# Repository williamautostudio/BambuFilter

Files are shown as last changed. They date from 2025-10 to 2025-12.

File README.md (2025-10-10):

# Air Filtration System – User Guide

## Table of Contents
- [Introduction](#introduction)  
- [Description](#description)  
  - [1. 3D Printing and Fan](#1-3d-printing-and-fan)  
    - [1.1 Printed Parts](#11-printed-parts)  
    - [1.2 Standard Components](#12-standard-components)  
    - [1.3 Key Components](#13-key-components)  
    - [1.4 Assembly](#14-assembly)  
  - [2. Fan Control Board](#2-fan-control-board)  
    - [2.1 PCB Layout](#21-pcb-layout)  
  - [3. ESP32 Firmware](#3-esp32-firmware)  
  - [4. Control Board Configuration and Operation](#4-control-board-configuration-and-operation)  
    - [4.1 Initial Configuration](#41-initial-configuration)  
      - [4.1.1 Accessing the Configuration Page](#411-accessing-the-configuration-page)  
      - [4.1.2 Wi-Fi Configuration](#412-wi-fi-configuration)  
      - [4.1.3 Configuration Parameters](#413-configuration-parameters)  
    - [4.2 Operation](#42-operation)  
      - [4.2.1 Web Interface](#421-web-interface)  
      - [4.2.2 Web API](#422-web-api)  
      - [4.2.3 MQTT Commands](#423-mqtt-commands)  
      - [4.2.4 Re-Configuration](#424-re-configuration)

---

## Introduction
Upgrade your **Bambu S1P** or **X1C 3D printer** with a smarter way to breathe clean air.  
This modular air filtration system features a **2-in-1 HEPA13 + activated carbon filter**, effectively removing fine particles and odors.  
Its modular structure allows for quick and easy filter replacement.

Unlike conventional filters, this system supports **intelligent fan control**.  
Connect to **Wi-Fi** to manage the fan remotely — turn it on/off, adjust speed, or monitor real-time status via:

- Built-in **Web UI**
- **RESTful Web API**
- **MQTT protocol** for automation
- Full integration with **Home Assistant**

This project is **fully open-source** and divided into three modular parts:

1. 3D-Printed Housing and Fan  
2. Fan Control Board  
3. ESP32 Firmware

---

## Description

### 1. 3D Printing and Fan

#### 1.1 Printed Parts
A total of **five 3D-printed components** are required.  
All 3D models are published on **MakerWorld** & **Github** — feel free to download and print them.  
If you do not require the fan-control function, you may omit printing the control-board enclosure.

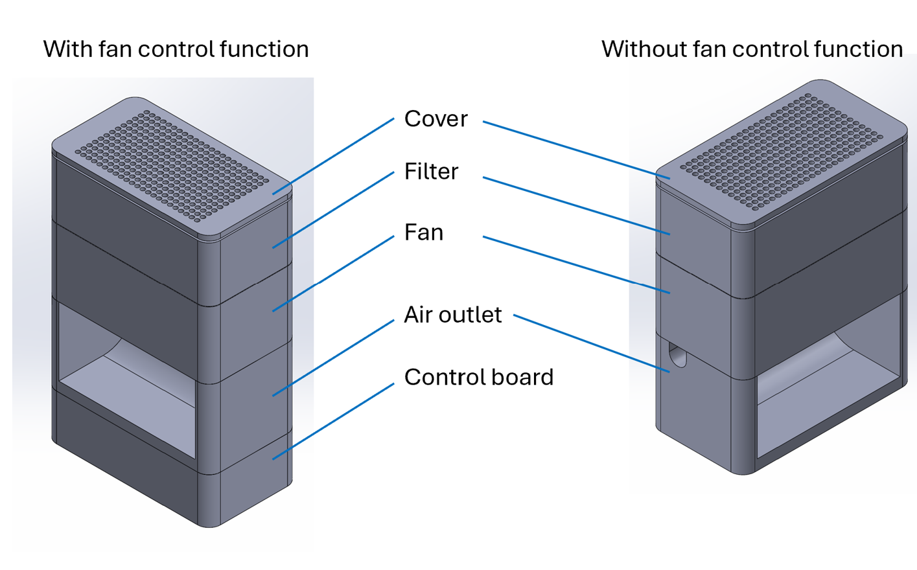
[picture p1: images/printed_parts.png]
Printed Parts


---

#### 1.2 Standard Components

| Item | Spec. / Model | Qty. | Note |
|:---|:---|:---:|:---|
| 1. Fan | 4028 DC 24 V / 4 wire, 18000 rpm | 2 | 1. 2-wire model optional 2. RPM lower than 18000 is fine. |
| 1.1 Screw | M3 × 35 mm | 8 (4) | 2 screws per fan are acceptable |
| 1.2 Nut | M3 | 8 (4) | — |
| 2. Filter | HEPA13 + Activated Carbon Air Filter | 1 | — |
| 3. PCB Board | Ref. Gerber file | 1 | — |
| 3.1 ESP32 | Seeed Studio XIAO ESP32-C3 | 1 | With external antenna |
| 3.2 DC-DC Regulator | MP1584EN DC-DC Regulator | 1 | Input 24 V, Output 5 V |
| 3.3 Terminal | 5.08 mm × 2 P | 3 | — |
| 3.4 IC Socket | 2.54 mm × 7 P | 2 | Optional |
| 3.5 Transistor | C945 (TO-92) | 1 | — |
| 3.6 Resistor | 10 kΩ 1/4 W | 2 | — |
| 3.7 Resistor | 1 kΩ 1/4 W | 1 | — |
| 4. Power Adaptor | Output DC 24 V 1 A | 1 | — |

---

#### 1.3 Key Components
- **Fan** – 4-wire model (2-wire optional)  
  [Where to buy?](https://detail.tmall.com/item.htm?id=695868124936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)
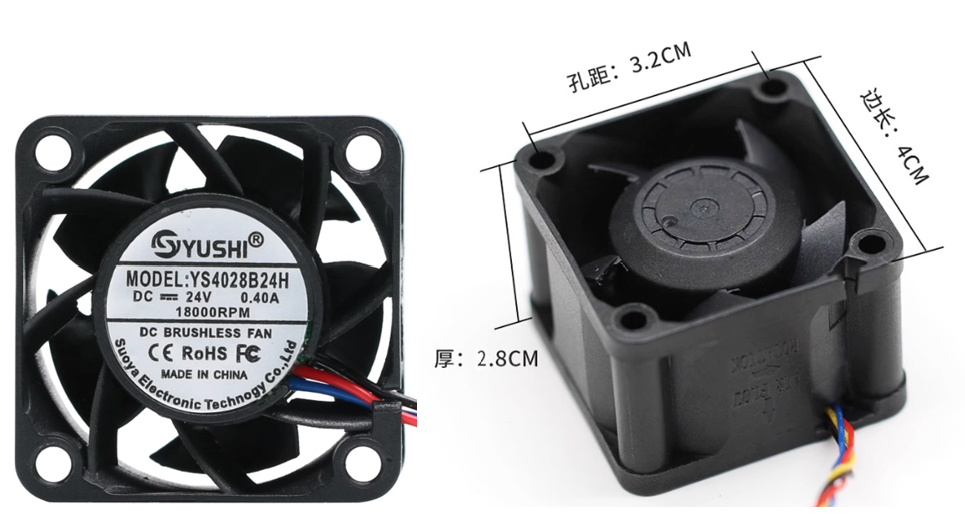
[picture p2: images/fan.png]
Fan
  

- **Filter** – HEPA13 + Carbon  
  [Where to buy?](https://item.taobao.com/item.htm?id=895551373211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)
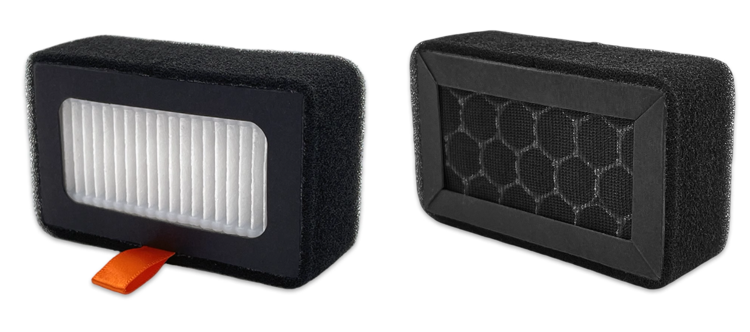
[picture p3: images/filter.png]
Filter
  

- **DC-DC Regulator** – MP1584EN   
  [Where to buy?](https://item.taobao.com/item.htm?id=662919695159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)
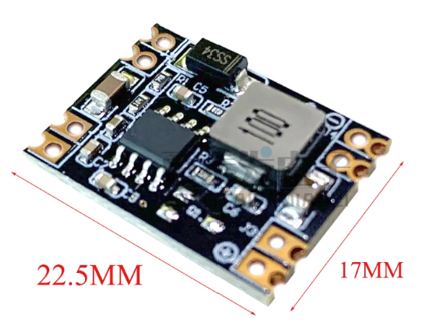
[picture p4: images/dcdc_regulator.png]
DC-DC Regulator
  

- **Seeed Studio XIAO ESP32-C3**   
  [Where to buy?](https://item.taobao.com/item.htm?id=679197017494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)
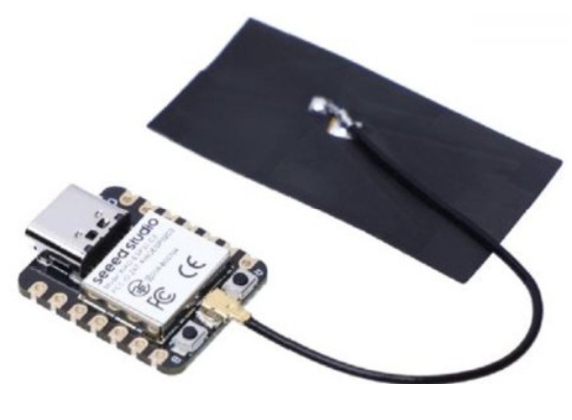
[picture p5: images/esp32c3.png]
ESP32-C3
  

- **Power Adapter** (DC 24 V)  
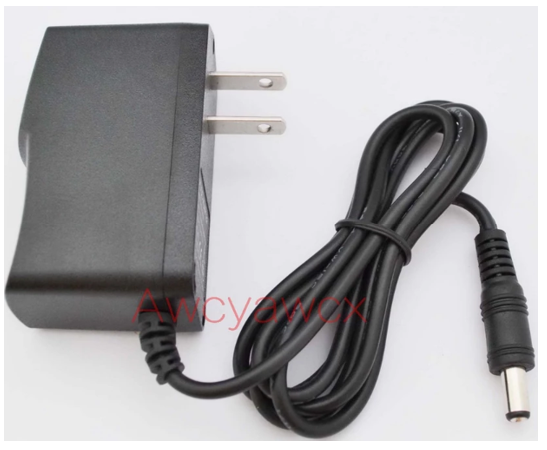
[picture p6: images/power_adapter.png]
Power Adapter
  

---

#### 1.4 Assembly

##### 1.4.1 With Fan Control Function
Install the control board, connect the ESP32, and wire the fan’s PWM control line according to the circuit layout.

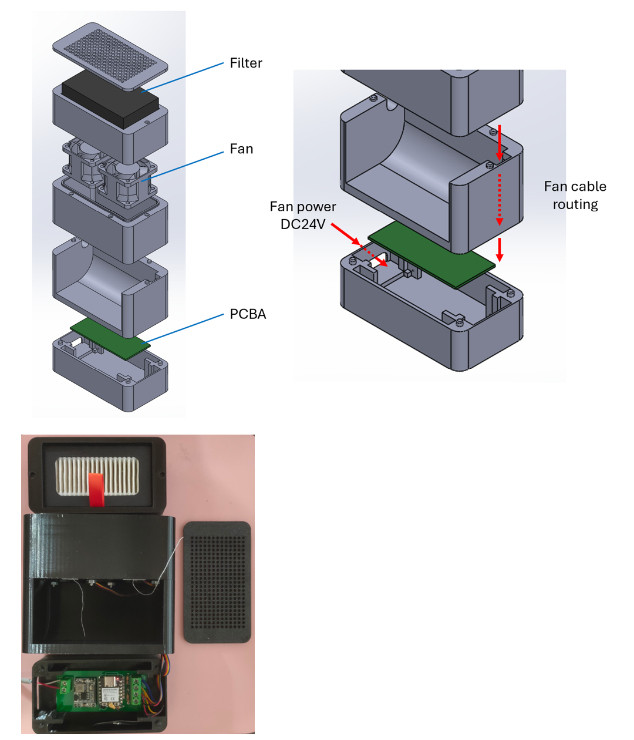
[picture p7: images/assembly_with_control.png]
Assembly With Control


##### 1.4.2 Without Fan Control Function
Connect the fan directly to a **DC 24 V power source** for constant operation.

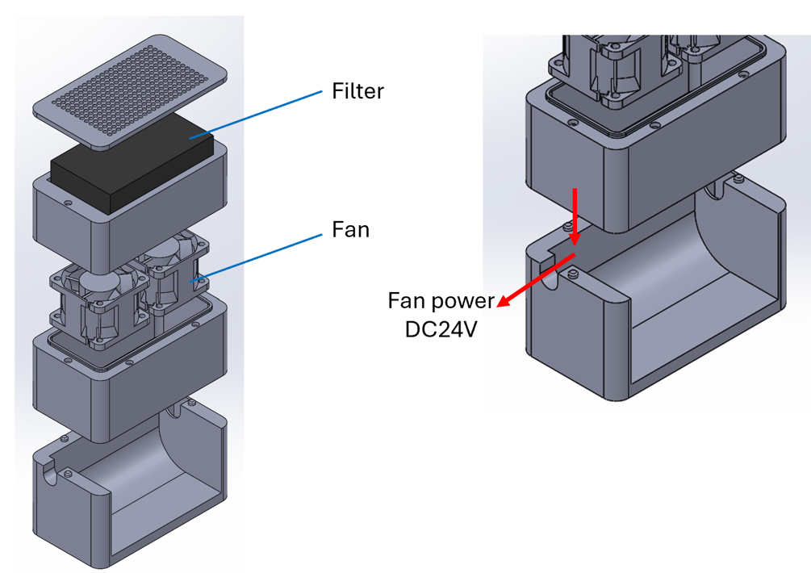
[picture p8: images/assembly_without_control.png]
Assembly Without Control


---

### 2. Fan Control Board

#### 2.1 PCB Layout (70.6 × 31.8 mm)
You may either:

- Solder an **IC socket** to the PCB and insert the ESP32 module, or  
- Solder the **ESP32 directly** to the board for **ease of assembly**.  
[Gerber file](https://github.com/williamautostudio/BambuFilter/tree/main/pcba)
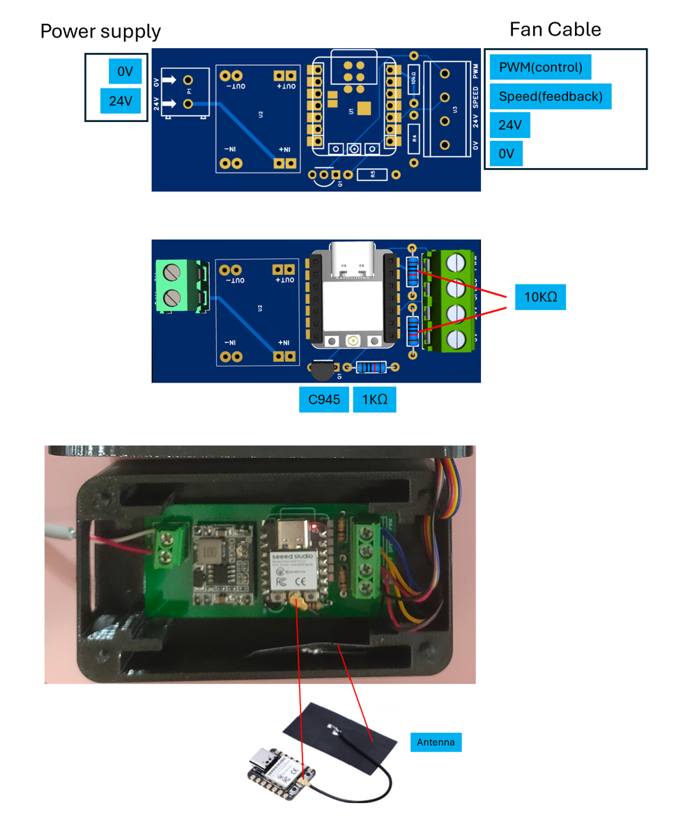
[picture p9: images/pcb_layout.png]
PCB Layout


---

### 3. ESP32 Firmware
Source code is available on [**GitHub**.](https://github.com/williamautostudio/BambuFilter/tree/main/firmware)

To build and upload the firmware:
1. Use **VS Code** with **PlatformIO**.  
2. Follow online tutorials for compiling and flashing if unfamiliar (not covered in this document).

---

### 4. Control Board Configuration and Operation

#### 4.1 Initial Configuration
Upon first power-up, the **ESP32** runs in **AP mode**.  
You can connect via browser to configure Wi-Fi and default fan settings.  

If configuration is skipped, the fan runs with **factory defaults**:
- Default speed : 50 %
- Fan auto-starts after power-on

---

##### 4.1.1 Accessing the Configuration Page
1. Power on the ESP32 —it starts in AP mode with SSID `BambuFanAP`.  
2. Connect your computer or phone to `BambuFanAP`.  
3. Open browser → `http://192.168.4.1` to access the configuration interface.

---

##### 4.1.2 Wi-Fi Configuration
Click **“Configure Wi-Fi”** to open the setup page.

> ⚠️ If the SSID disconnects, reconnect to `BambuFanAP`.  
> The ESP32’s web server may respond slowly — please wait rather than clicking repeatedly.  
> If no response within 3 minutes, **power-cycle** the device and retry.

---

##### 4.1.3 Configuration Parameters
- **Wi-Fi Settings** — SSID and Password  
- **Fan Default Speed** — 15 %–100 % (default 50 %)  
- **Fan Default ON** — whether fan turns on automatically after power-on  
  - `True` = ON by default  
  - `False` = manual activation via Web API / MQTT / Web UI  
- Click **Save** to store settings.

---

#### 4.2 Operation

##### 4.2.1 Web Interface
- **Default ON at Power-Up** – Defines auto-start behavior.  
- **Turn On / Turn Off** – Manual fan control; speed retains last setting.  
- **Fan Speed** – Adjust 15 %–100 %. Below 15 % auto-corrects to 15 %.  
  - If below 25 %, starts at 25 % briefly for stable startup.

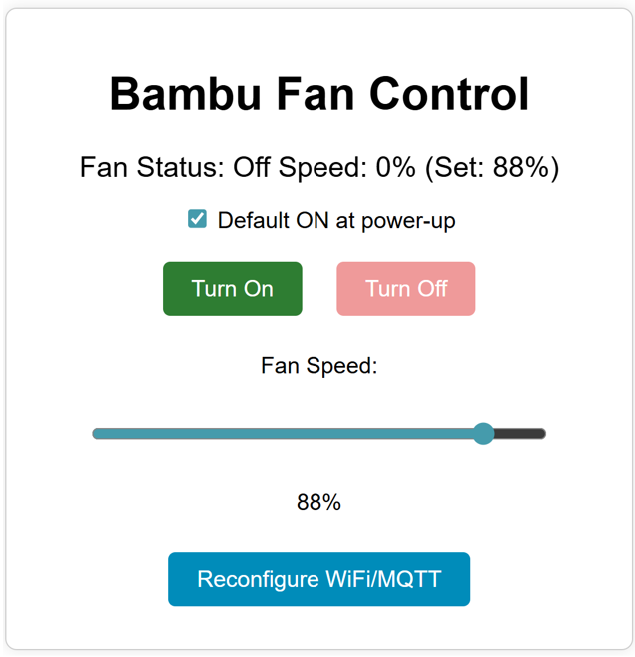
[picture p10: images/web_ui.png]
Web Interface


---

##### 4.2.2 Web API
Assuming ESP32 IP = `192.168.1.2`:

| Function | Endpoint |
|:---|:---|
| Enable Default ON | `http://192.168.1.2/fan?default_on=true` |
| Disable Default ON | `http://192.168.1.2/fan?default_on=false` |
| Turn On Fan | `http://192.168.1.2/fan?state=on` |
| Turn Off Fan | `http://192.168.1.2/fan?state=off` |
| Set Fan Speed 70 % | `http://192.168.1.2/fan?speed=70` |

---

##### 4.2.3 MQTT Commands
- **Default Topic:** `bambu/p1s/fan/cmd`  
- **Payload Format:** Raw numeric value  

**Examples:**
```text
Set speed 70 % → cmd = 70  
Stop fan → cmd = 0
```

---

##### 4.2.4 Re-Configuration
Click **“Reconfigure Wi-Fi / MQTT”** to update settings without rebooting.  

> ⚠️ Note: Each time you enter the configuration page, re-enter Wi-Fi SSID and password.

---

✅ **End of Document**

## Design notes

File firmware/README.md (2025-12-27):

# Bambu P1S Fan Control (ESP32C3)

This project provides firmware for a Seeed XIAO ESP32C3 microcontroller to control a 4-wire PWM fan, specifically designed for use with the Bambu Lab P1S. It connects to WiFi, uses MQTT for communication, and supports Over-The-Air (OTA) updates.

## Features

*   **WiFi Connectivity**: Connects to your local WiFi network, configurable via a web portal if no network is found or if re-configured.
*   **MQTT Control**: Remotely control fan speed via MQTT messages (bidirectional communication).
*   **4-wire PWM Fan Control**: Accurately controls fan speed using PWM.
*   **Active-low PWM**: Handles active-low PWM signals common in 4-wire fans.
*   **Configurable Fan Thresholds**: Adjustable minimum fan speeds for startup and continuous operation.
*   **Over-The-Air (OTA) Updates**: Update firmware wirelessly.
*   **MQTT State Reporting**: Publishes current fan speed (duty and percentage) to an MQTT topic.
*   **Last Will and Testament (LWT)**: Reports device online/offline status via MQTT.
*   **Web Configuration Portal**: Automatically launches a web interface (Access Point: "BambuFanAP", password: "password") for easy setup of WiFi credentials, MQTT server details, and fan default behavior (on/off, speed).
*   **Web Control Interface & HTTP API**: Provides a web page to monitor fan status (on/off, speed), manually turn the fan on/off, and adjust speed. An HTTP API (`/fan?state=on|off`, `/fan?speed=X`, or `/fan?default_on=true|false`) is also available for remote control, including setting the "Default ON at power-up" state.
*   **Reconfigure Option**: A button on the web interface allows the device to re-enter the configuration portal without resetting existing WiFi settings, enabling easy modification of MQTT and fan defaults.
*   **Persistent Fan Speed**: The last set fan speed is stored and used when the fan is turned on.

This project involves a custom PCB design for the fan control.

## Hardware

*   **Microcontroller**: Seeed XIAO ESP32C3
*   **Fan**: 4-wire PWM fan (DC24V 4028 18000rpm)
*   **Power Supply**: DC24V 1A
*   **PCB**: 71x32mm
*   **Fan Control Box**: 3D printed
*   **Filter**: 拓竹HEPA13活性碳空氣濾心(淘寶)

## Software Requirements

*   PlatformIO IDE Extension for VS Code or PlatformIO Core CLI.

## Configuration

All configuration parameters (WiFi credentials, MQTT server details, MQTT username/password, and fan default behavior) are now managed through a web configuration portal provided by `WiFiManager`. This portal automatically launches if the device cannot connect to a known WiFi network, or can be manually triggered via a button on the web control interface.

### Accessing the Configuration Portal

1.  **Automatic**: If the ESP32 cannot connect to a saved WiFi network, it will create an Access Point (AP) named "BambuFanAP" with the password "password". Connect to this AP with your phone or computer.
2.  **Manual**: Access the web control interface (once connected to WiFi) and click the "Reconfigure WiFi/MQTT" button. If the captive portal does not open automatically after connecting to the ESP32 access point, open `http://192.168.4.1` in your web browser.

Once connected to the AP, a captive portal should automatically open in your browser, allowing you to set:

*   **WiFi SSID & Password**
*   **MQTT Server IP/Hostname & Port**
*   **MQTT Username & Password**
*   **Fan Default Speed (0-100%)**
*   **Fan Default ON/OFF**

### PWM/LEDC Settings (Hardcoded)

The following settings are currently hardcoded in `src/main.cpp`:

*   `FAN_PWM_PIN`: GPIO pin connected to the fan's PWM signal (default: 10).
*   `PWM_FREQ_HZ`: PWM frequency in Hz (default: 25000).
*   `PWM_RES_BITS`: PWM resolution in bits (default: 10, for 0-1023 duty cycle).
*   `PCT_MIN_START`: Minimum percentage to start the fan from 0 (default: 25).
*   `PCT_MIN_RUN`: Minimum percentage to keep the fan running (default: 15).

## MQTT Usage

Send messages to `TOPIC_CMD_SPEED` to control the fan:

*   **Percentage (0-100)**: Send a plain number string (e.g., `"60"` for 60% speed).
    *   If the fan is currently off (0 duty) and the new percentage is greater than 0 but less than `PCT_MIN_START`, `PCT_MIN_START` will be used instead.
*   **Raw Duty Cycle (0-1023)**: Send `RAW:<value>` (e.g., `"RAW:512"` for ~50% duty cycle).
*   **JSON Object**: Send a JSON string with `speed` or `percent` field (e.g., `{"speed": 75}` or `{"percent": 75}`).
    *   Similar minimum startup logic applies for percentage values.

The fan's current state (duty cycle and percentage) will be published to `TOPIC_STATE_SPEED`.

## OTA (Over-The-Air) Updates

The device supports OTA updates. Ensure that `upload_protocol = espota` and `upload_port` are correctly configured in `platformio.ini` (e.g., `upload_port = 192.168.2.161`). The hostname for OTA is set to `esp32`.

## Manufacturing information

*   **`image/`**: Contains images related to the project.
    *   `pcb_layout.jpg`: A layout image of the PCB.
    *   `fan_control_box.jpg`: A cutout image of the fan's mechanical components.
    *   `fan.jpg`: A photo of the fan.
    *   `filter.jpg`: A photo of the filter.
*   **`PCB/`**: Contains the Gerber files for the fan control PCB board.
*   **`SolidWorks/`**: Contains the SolidWorks 3D design files for the fan's mechanical components.

## PCB Design

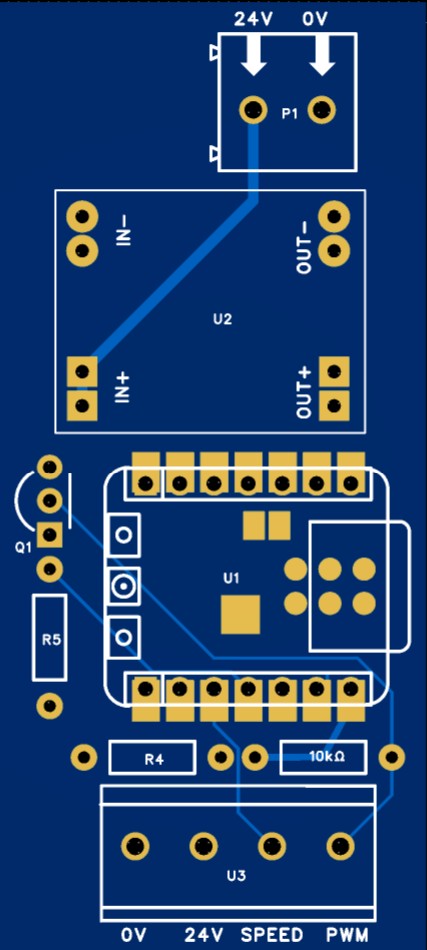
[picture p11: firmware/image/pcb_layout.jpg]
PCB Layout


The PCB layout can be viewed and edited online: [PCB Layout Editor - EasyEDA](https://pro.easyeda.com/editor#id=c79e3e0623a544f8a684775a9b8ccbd5,tab=*d06ea5cc8f37423995d957d8589f9b6b@c79e3e0623a544f8a684775a9b8ccbd5)

## Mechanical Design

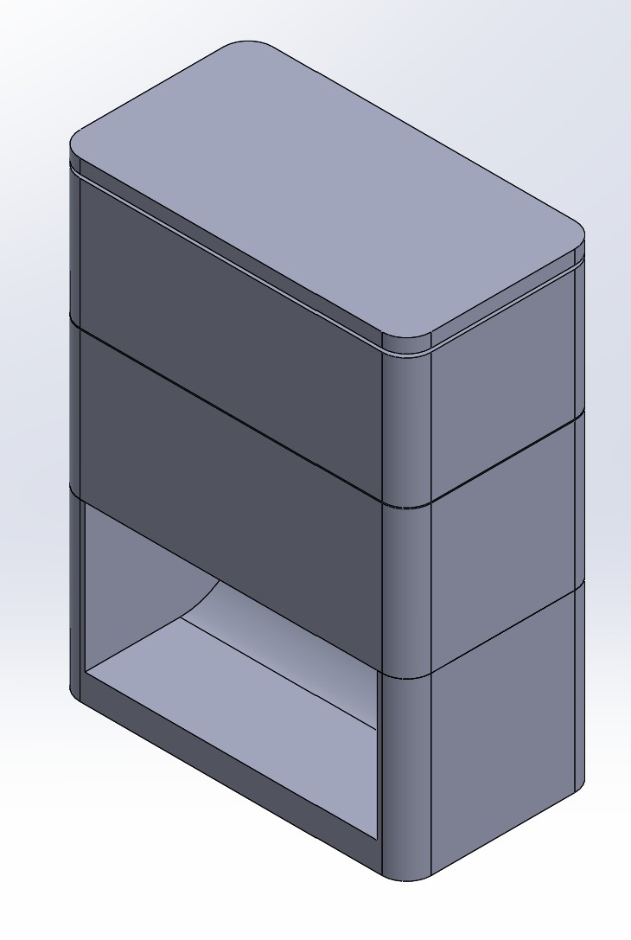
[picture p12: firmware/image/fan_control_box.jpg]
Fan Control Box


## Fan

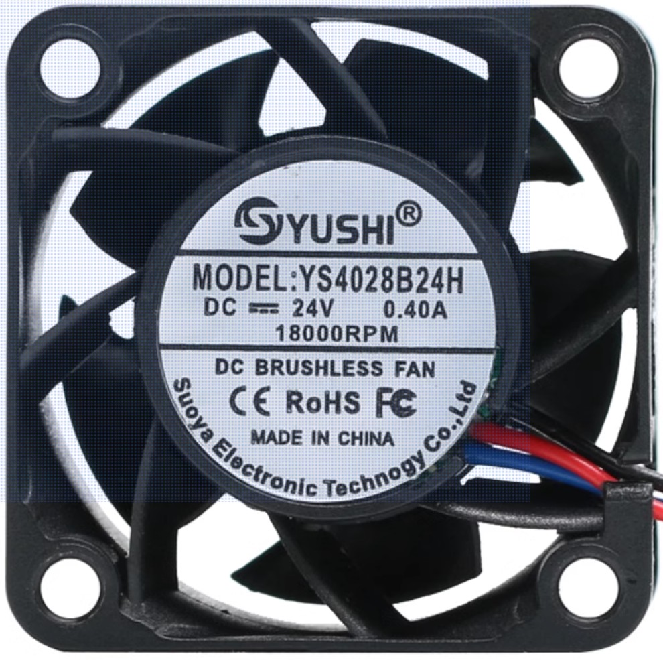
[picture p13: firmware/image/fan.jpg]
Fan

[淘寶](https://detail.tmall.com/item.htm?id=695868124936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)

## Filter

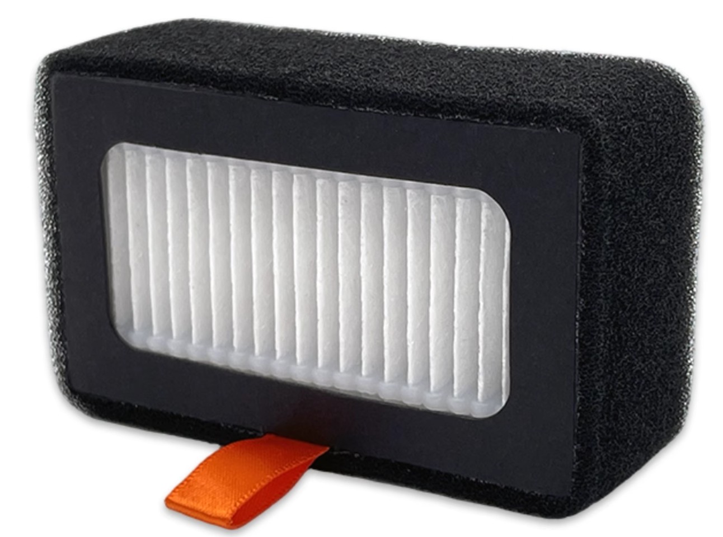
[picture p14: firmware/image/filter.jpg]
Filter

[淘寶](https://item.taobao.com/item.htm?id=895551373211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)

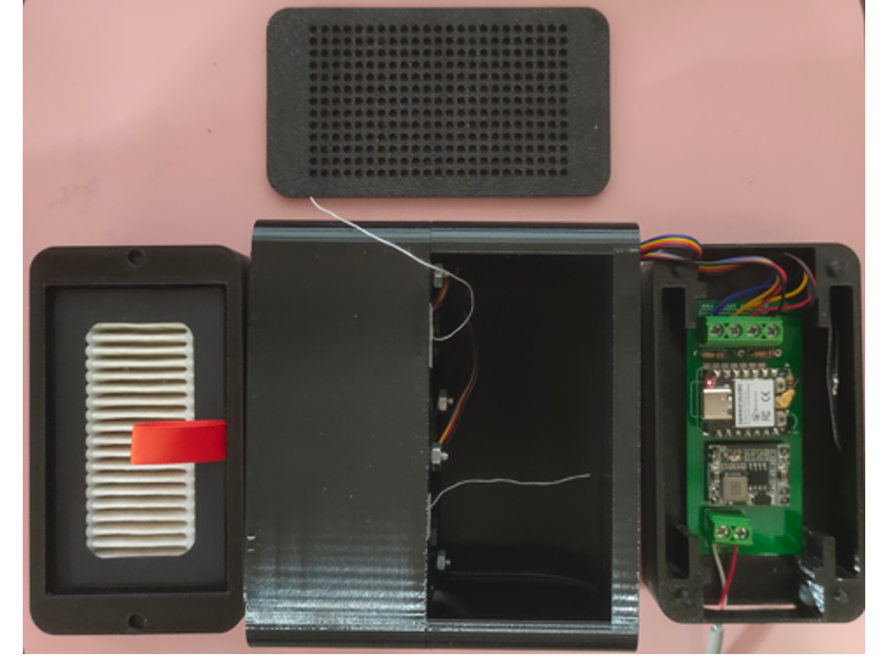
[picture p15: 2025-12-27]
images/cover/Pic3.png

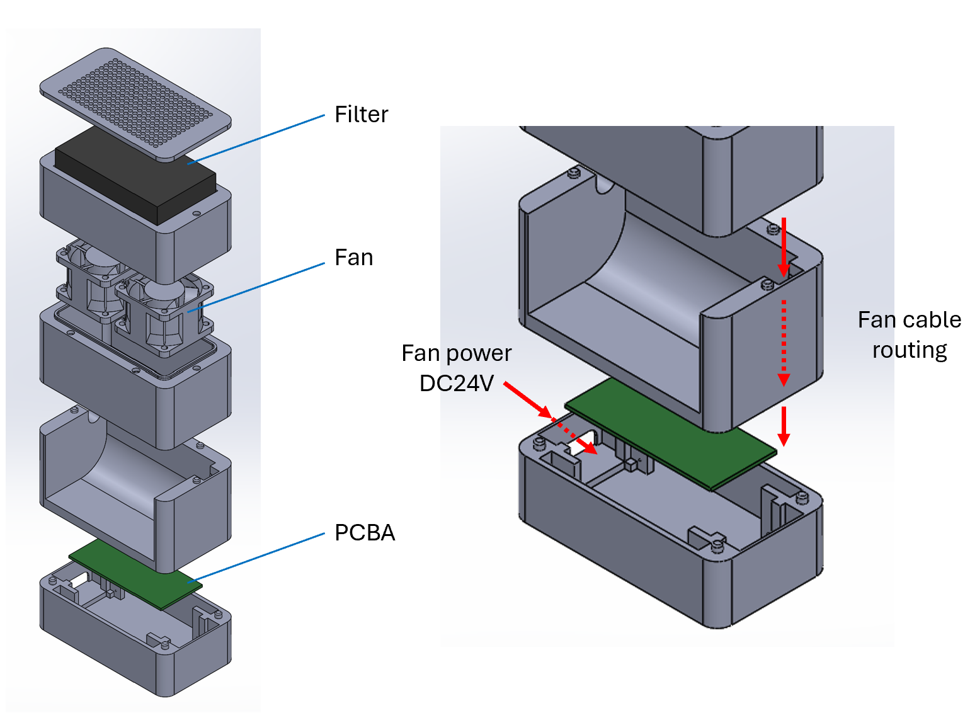
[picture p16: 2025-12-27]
images/cover/Pic1.png

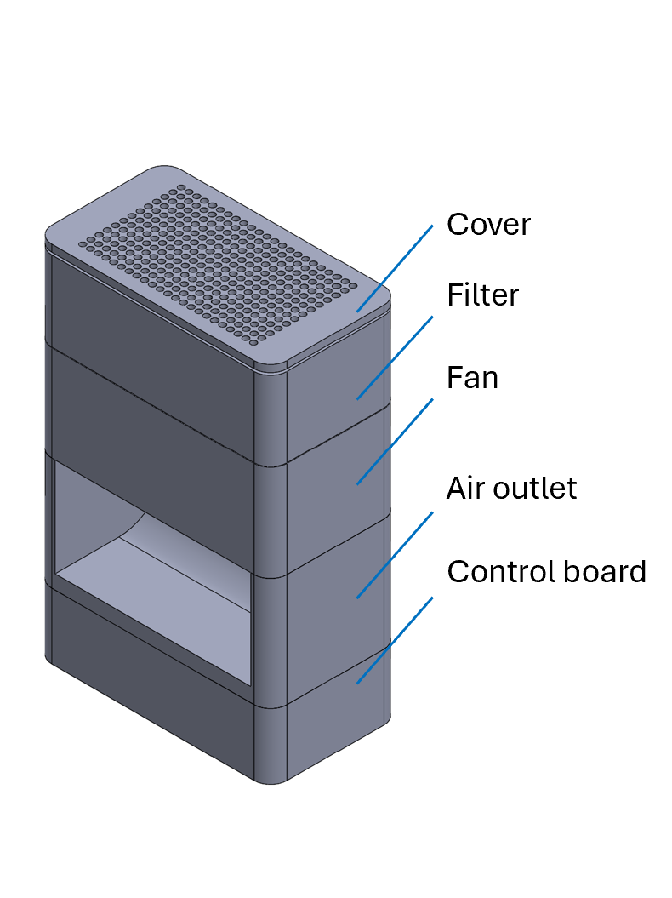
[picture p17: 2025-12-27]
images/cover/cover 3-4.png

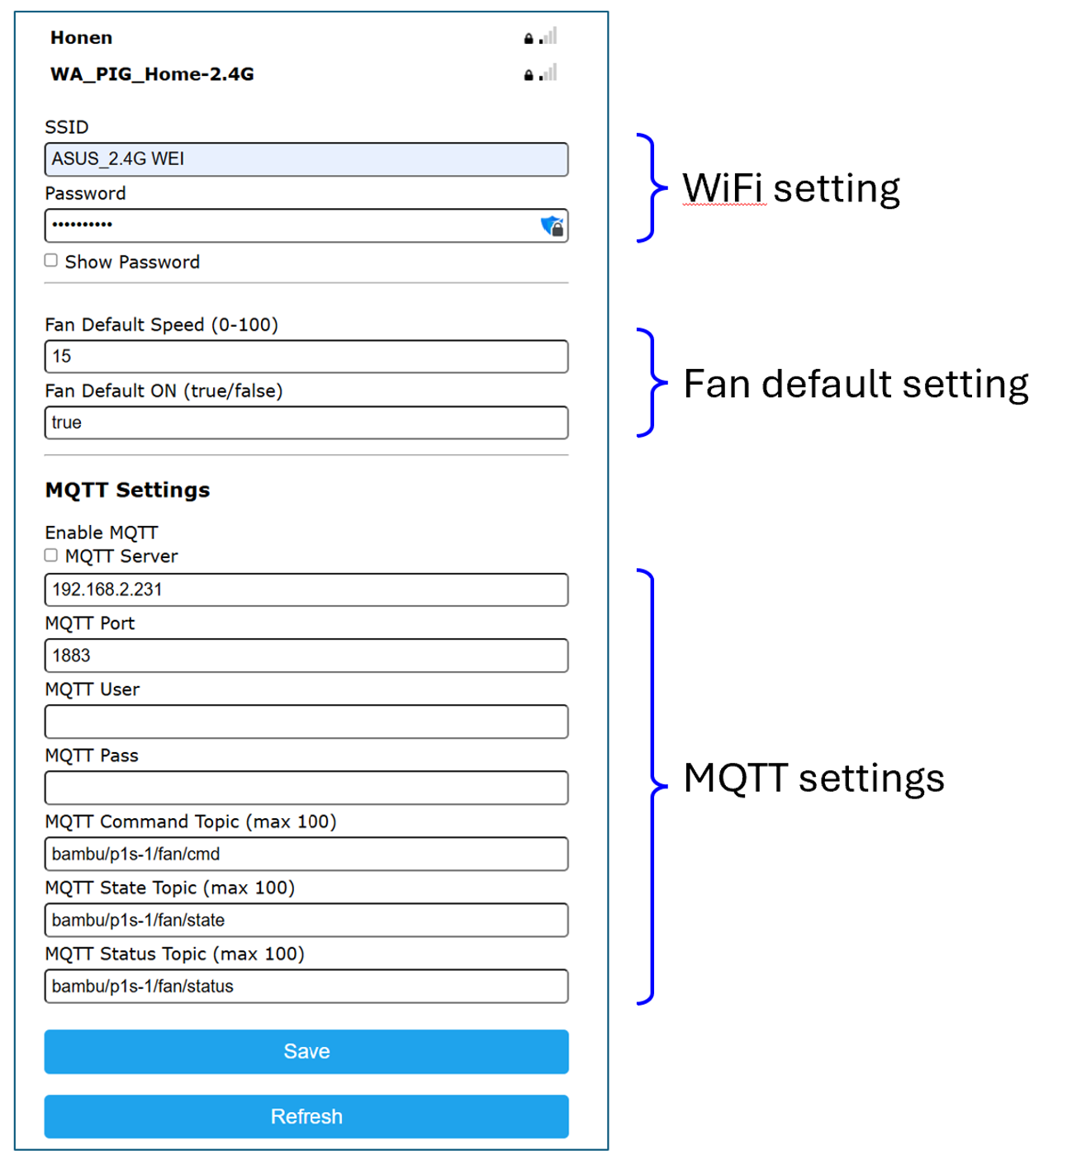
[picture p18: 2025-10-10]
images/parameters.png

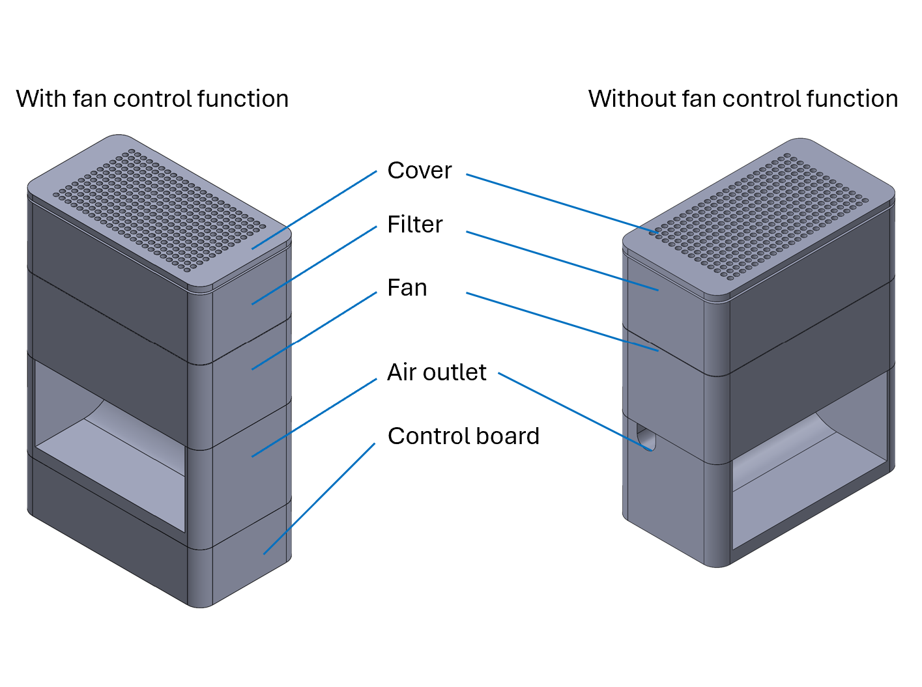
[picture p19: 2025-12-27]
images/cover/cover 4-3.png

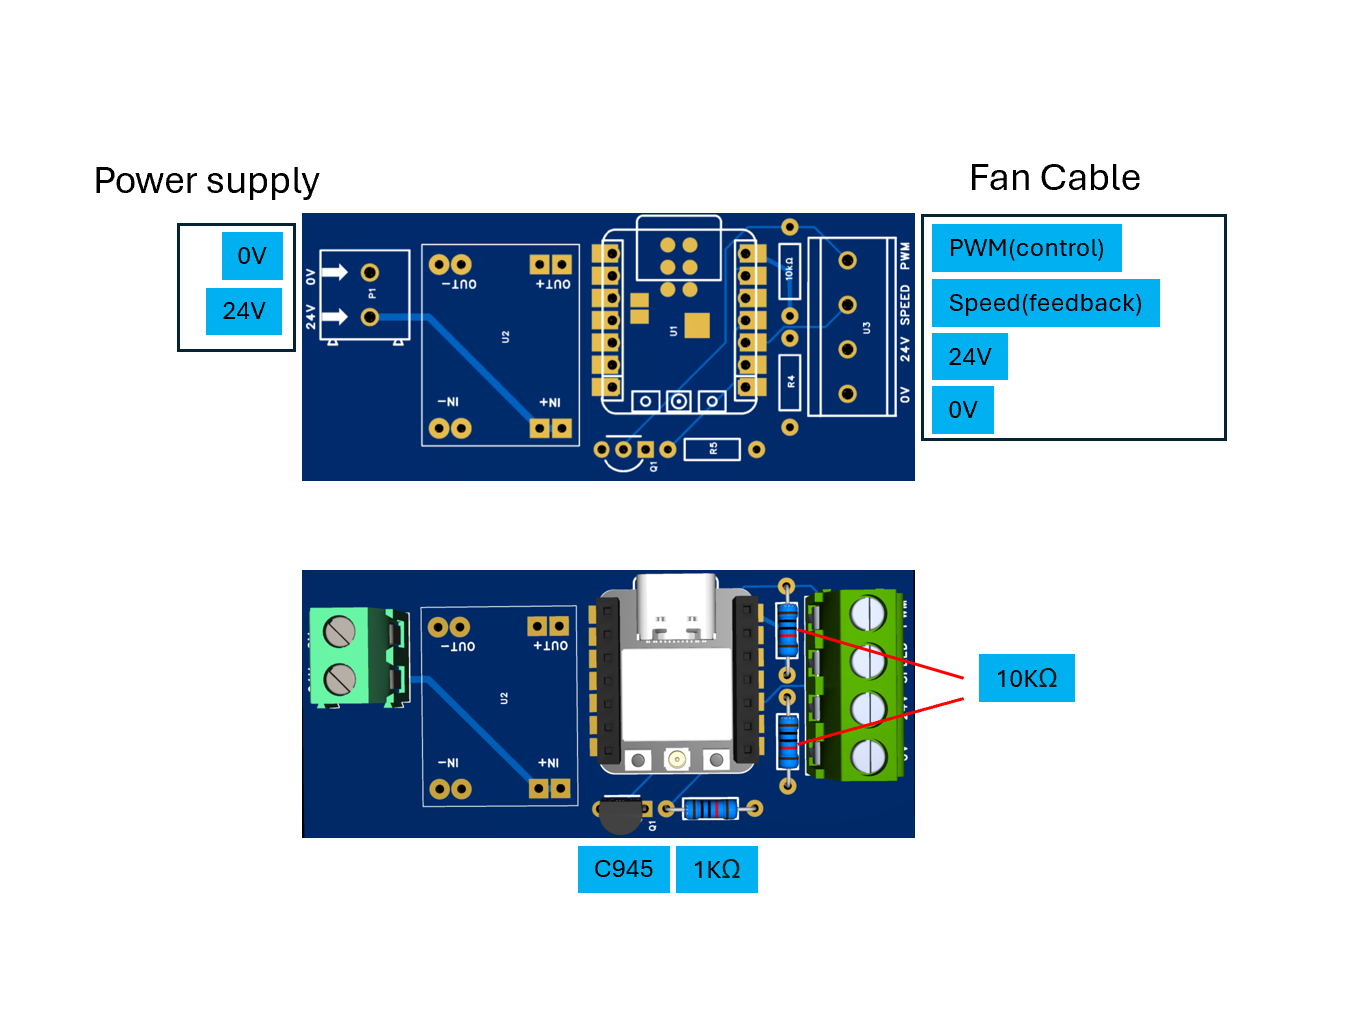
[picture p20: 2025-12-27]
images/cover/Pic4.png

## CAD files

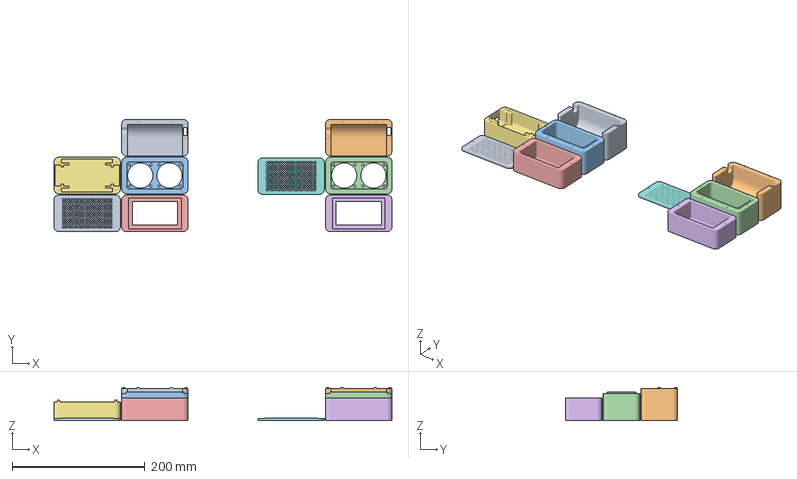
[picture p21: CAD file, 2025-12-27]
Bambu project/Bambu filter.3mf
509.2 x 169.0 x 50.0 mm
air outlet x 2
fan x 2
filter x 2
control board
cover x 2

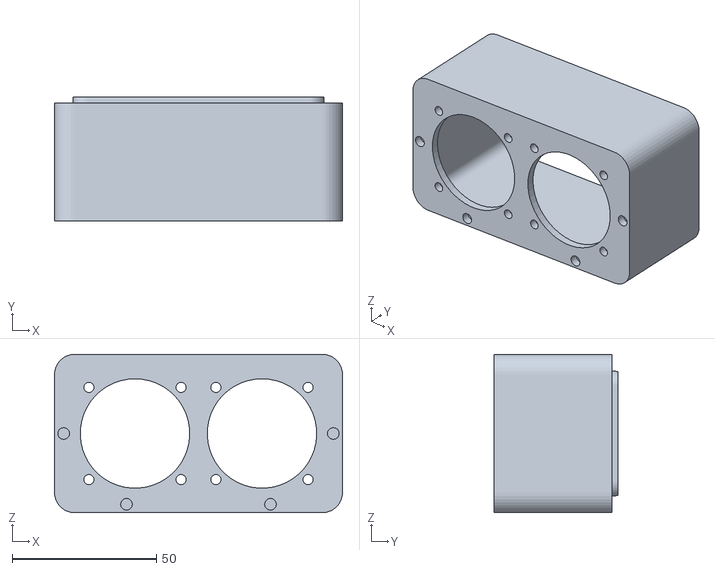
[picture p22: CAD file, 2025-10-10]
Bambu project/A01 - P02-1.STL
100.0 x 43.0 x 55.0

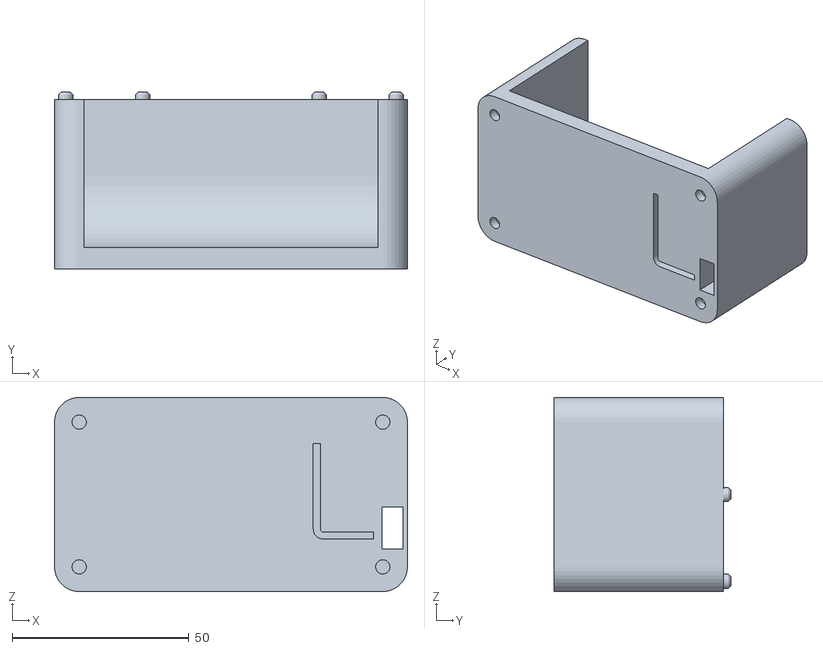
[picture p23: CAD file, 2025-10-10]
Bambu project/A01 - P04-1.STL
100.0 x 50.0 x 55.0

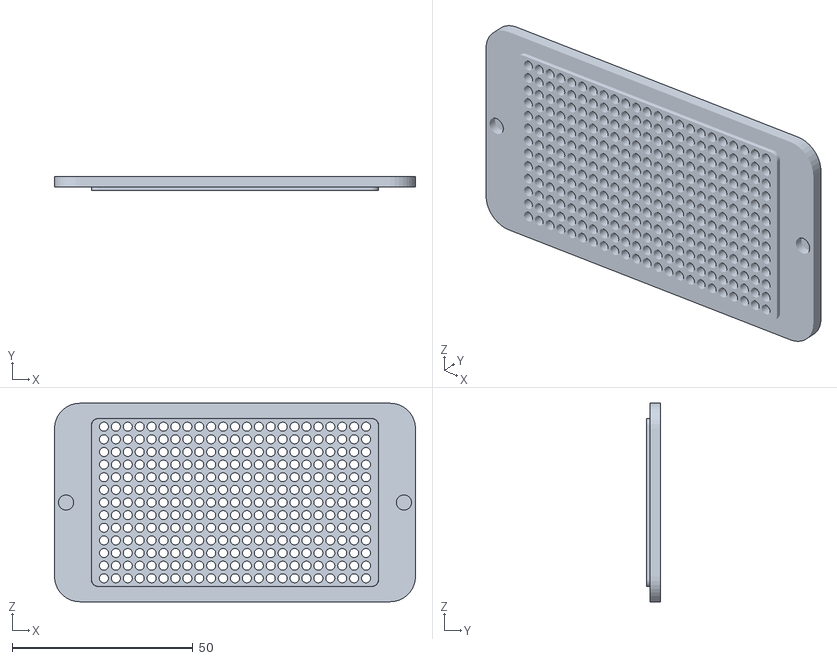
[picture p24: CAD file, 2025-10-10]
Bambu project/A01 - P03-1.STL
100.0 x 4.00 x 55.0

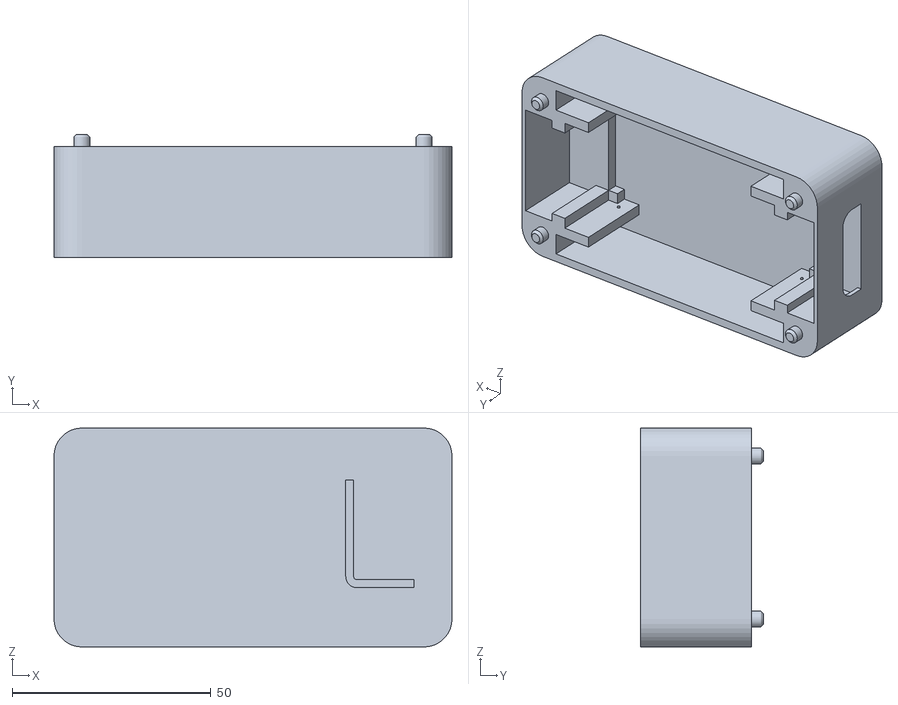
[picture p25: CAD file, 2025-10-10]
Bambu project/A01 - P05-1.STL
100.0 x 31.0 x 55.0

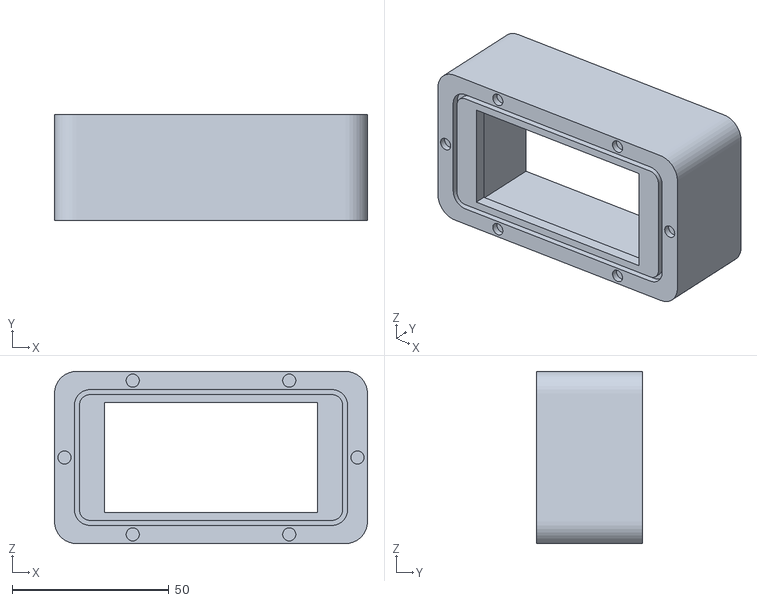
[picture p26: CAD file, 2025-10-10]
Bambu project/A01 - P01-1.STL
100.0 x 34.0 x 55.0

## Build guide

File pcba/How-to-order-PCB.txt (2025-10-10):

How to Order PCB

Please refer to:
https://prodocs.easyeda.com/en/pcb/order-order-pcb/index.html

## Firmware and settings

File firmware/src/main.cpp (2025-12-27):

#include <Arduino.h>
#include <WiFi.h>
#include <PubSubClient.h>
#include <ArduinoOTA.h>
#include <DNSServer.h>
#include <WebServer.h>
#include <WiFiManager.h>
#include <Preferences.h>
#include <cstring>
#include <ctype.h>
#include <esp_system.h>
#include <cstdarg>

#include <cstdio>

// ========= Globals =========
WiFiClient espClient;
PubSubClient mqtt(espClient);
WebServer server(80);
WiFiManager wifiManager;

bool mqttWasConnected = false;
unsigned long lastMqttAttemptMs = 0;
constexpr unsigned long MQTT_RETRY_INTERVAL_MS = 5000;
wl_status_t lastWifiStatus = WL_IDLE_STATUS;
bool mqttStateDirty = false;
int pendingDutyActiveHigh = 0;
char mqttClientId[32] = "";
int pendingPercentAfterStart = 0;
unsigned long pendingPercentApplyMs = 0;
constexpr uint32_t SOFT_START_SETTLE_MS = 800;

// ========= FWD declarations =========
void loadConfig();
void saveConfig();
void applyConfigToParameters();
bool updateConfigFromParameters();
bool parseBoolParam(const char* value);
int  percentToDuty(int pct);
int  invertDuty(int duty);
void ensureMqtt();
void setupPwm();
void handleRoot();
void handleFanApi();
void handleStatusApi();
void handleReconfig();
void notFound();
void configModeCallback(WiFiManager *myWiFiManager);
void saveConfigCallback();
void applyPowerOnPolicy();
void writeDutyActiveLow(int dutyActiveHigh);
void publishStateFromDuty(int dutyActiveHigh);
void publishMqttStatus(const char* status);
void handleFanSpeed(int percent);

// ===== Serial logging helpers =====
template <typename T>
void logPrint(const T& value) { Serial.print(value); }

template <typename T>
void logPrintln(const T& value) { Serial.println(value); }

void logPrintf(const char* fmt, ...) {
  char buffer[256];
  va_list args;
  va_start(args, fmt);
  vsnprintf(buffer, sizeof(buffer), fmt, args);
  va_end(args);
  Serial.print(buffer);
}

// ========= Config & Parameters =========
Preferences preferences;
struct Config {
  bool mqtt_enabled;                 // NEW: master toggle (default false)
  char mqtt_host[40];
  int  mqtt_port;
  char mqtt_user[40];
  char mqtt_pass[40];
  char mqtt_command_topic[100];
  char mqtt_state_topic[100];
  char mqtt_status_topic[100];
  int  fan_default_speed_pct;
  bool fan_default_on;
} currentConfig;

constexpr int MQTT_HOST_PARAM_LEN   = 40;
constexpr int MQTT_PORT_PARAM_LEN   = 6;
constexpr int MQTT_USER_PARAM_LEN   = 40;
constexpr int MQTT_PASS_PARAM_LEN   = 40;
constexpr int MQTT_TOPIC_PARAM_LEN  = 100;
constexpr int FAN_DEFAULT_SPEED_PARAM_LEN = 4;
constexpr int FAN_DEFAULT_ON_PARAM_LEN    = 6;

// NEW: robust checkbox implementation using a hidden field + UI checkbox synced via JS
// Hidden field actually submitted to WiFiManager (value '1' or '0')
WiFiManagerParameter custom_mqtt_enable_hidden("use_mqtt", "", "0", 2, "type='hidden'");
// UI block with checkbox and a small script to mirror to hidden field
WiFiManagerParameter custom_mqtt_enable_ui(
  "<div style='margin:8px 0;display:flex;align-items:center;gap:8px;'><input type='checkbox' id='use_mqtt_cb'><span>Enable MQTT</span></div>"
  "<script>(function(){var cb=document.getElementById('use_mqtt_cb');var hid=document.getElementById('use_mqtt');if(!cb||!hid)return;cb.checked=(hid.value==='1');cb.addEventListener('change',function(){hid.value=cb.checked?'1':'0';});})();</script>"
);

// Non‑MQTT parameters first (so MQTT block can be placed at the very bottom of the portal)
WiFiManagerParameter custom_fan_def_spd("fspd", "Fan Default Speed (15-100)", "", FAN_DEFAULT_SPEED_PARAM_LEN);
WiFiManagerParameter custom_fan_def_on ("fdon", "Fan Default ON (true/false)", "", FAN_DEFAULT_ON_PARAM_LEN);

// MQTT parameters (grouped together, added last in setup so they appear at the bottom)
WiFiManagerParameter custom_mqtt_header("<hr><h3>MQTT Settings</h3>");
WiFiManagerParameter custom_mqtt_host("mqtt_host", "MQTT Server", "", MQTT_HOST_PARAM_LEN);
WiFiManagerParameter custom_mqtt_port("mqtt_port", "MQTT Port", "", MQTT_PORT_PARAM_LEN);
WiFiManagerParameter custom_mqtt_user("mqtt_user", "MQTT User", "", MQTT_USER_PARAM_LEN);
WiFiManagerParameter custom_mqtt_pass("mqtt_pass", "MQTT Pass", "", MQTT_PASS_PARAM_LEN, "type='password'");
WiFiManagerParameter custom_mqtt_cmd_topic   ("cmdtopic",    "MQTT Command Topic (max 100)", "", MQTT_TOPIC_PARAM_LEN);
WiFiManagerParameter custom_mqtt_state_topic ("statetopic",  "MQTT State Topic (max 100)",   "", MQTT_TOPIC_PARAM_LEN);
WiFiManagerParameter custom_mqtt_status_topic("statustopic", "MQTT Status Topic (max 100)",  "", MQTT_TOPIC_PARAM_LEN);

// ========= PWM / Fan runtime =========
// static const int  FAN_PWM_PIN = 18;
#if defined(ARDUINO_ESP32C3_DEV)
  static const int  FAN_PWM_PIN = 10;
#else
  static const int  FAN_PWM_PIN = 18;
#endif

static const int  LEDC_CHANNEL   = 0;
// int pwmChannel = -1;
static const int  LEDC_TIMER     = 0;
static const uint32_t PWM_FREQ_HZ = 25000;
// static const uint32_t PWM_FREQ_HZ = 200;
static const uint8_t  PWM_RES_BITS = 10;

static const int PCT_MIN_START = 25;
static const int PCT_MIN_RUN   = 15;

int currentDuty = 0;
int currentPercent = 0;
int lastUserPercent = 0;

// ========= Config I/O =========
void loadConfig() {
  preferences.begin("fan-control", false);
  currentConfig.mqtt_enabled = preferences.getBool("mqtt_enabled", false);  // default false

  preferences.getString("mqtt_host", currentConfig.mqtt_host, sizeof(currentConfig.mqtt_host));
  currentConfig.mqtt_port = preferences.getInt("mqtt_port", 1883);
  preferences.getString("mqtt_user", currentConfig.mqtt_user, sizeof(currentConfig.mqtt_user));
  preferences.getString("mqtt_pass", currentConfig.mqtt_pass, sizeof(currentConfig.mqtt_pass));

  logPrintf("[%.3f ms] loadConfig: loaded mqtt_user='%s' (len: %d), mqtt_pass='%s' (len: %d)\n",
            millis() / 1000.0f,
            currentConfig.mqtt_user, strlen(currentConfig.mqtt_user),
            currentConfig.mqtt_pass, strlen(currentConfig.mqtt_pass));

  preferences.getString("cmd_topic",    currentConfig.mqtt_command_topic, sizeof(currentConfig.mqtt_command_topic));
  preferences.getString("state_topic",  currentConfig.mqtt_state_topic,   sizeof(currentConfig.mqtt_state_topic));
  preferences.getString("status_topic", currentConfig.mqtt_status_topic,  sizeof(currentConfig.mqtt_status_topic));
  currentConfig.fan_default_speed_pct = preferences.getInt("fan_def_spd", 50);
  currentConfig.fan_default_on        = preferences.getBool("fan_def_on", true);
  preferences.end();

  if (strlen(currentConfig.mqtt_host) == 0) {
    strncpy(currentConfig.mqtt_host, "192.168.2.231", sizeof(currentConfig.mqtt_host));
    currentConfig.mqtt_host[sizeof(currentConfig.mqtt_host) - 1] = '\0';
  }
  if (strlen(currentConfig.mqtt_command_topic) == 0) {
    strncpy(currentConfig.mqtt_command_topic, "bambu/p1s/fan/cmd", sizeof(currentConfig.mqtt_command_topic));
    currentConfig.mqtt_command_topic[sizeof(currentConfig.mqtt_command_topic) - 1] = '\0';
  }
  if (strlen(currentConfig.mqtt_state_topic) == 0) {
    strncpy(currentConfig.mqtt_state_topic, "bambu/p1s/fan/state", sizeof(currentConfig.mqtt_state_topic));
    currentConfig.mqtt_state_topic[sizeof(currentConfig.mqtt_state_topic) - 1] = '\0';
  }
  if (strlen(currentConfig.mqtt_status_topic) == 0) {
    strncpy(currentConfig.mqtt_status_topic, "bambu/p1s/fan/status", sizeof(currentConfig.mqtt_status_topic));
    currentConfig.mqtt_status_topic[sizeof(currentConfig.mqtt_status_topic) - 1] = '\0';
  }
  if (strlen(currentConfig.mqtt_user) == 0) currentConfig.mqtt_user[0] = '\0';
  if (strlen(currentConfig.mqtt_pass) == 0) currentConfig.mqtt_pass[0] = '\0';

  currentConfig.fan_default_speed_pct = constrain(currentConfig.fan_default_speed_pct, 0, 100);
  if (currentConfig.fan_default_speed_pct > 0 && currentConfig.fan_default_speed_pct < PCT_MIN_RUN) {
    currentConfig.fan_default_speed_pct = PCT_MIN_RUN;
  }

  lastUserPercent = currentConfig.fan_default_speed_pct;
  applyConfigToParameters();
}

void saveConfig() {
  float t = millis() / 1000.0f;
  preferences.begin("fan-control", false);

  // Snapshot old values
  bool   old_mqtt_enabled = preferences.getBool("mqtt_enabled", false);
  String old_mqtt_host    = preferences.getString("mqtt_host", "");
  int    old_mqtt_port    = preferences.getInt("mqtt_port", 1883);
  String old_mqtt_user    = preferences.getString("mqtt_user", "");
  String old_mqtt_pass    = preferences.getString("mqtt_pass", "");
  String old_cmd_topic    = preferences.getString("cmd_topic", "");
  String old_state_topic  = preferences.getString("state_topic", "");
  String old_status_topic = preferences.getString("status_topic", "");
  int    old_def_spd      = preferences.getInt("fan_def_spd", 50);
  bool   old_def_on       = preferences.getBool("fan_def_on", true);

  // Write new values
  preferences.putBool  ("mqtt_enabled", currentConfig.mqtt_enabled);
  preferences.putString("mqtt_host",    currentConfig.mqtt_host);
  preferences.putInt   ("mqtt_port",    currentConfig.mqtt_port);
  preferences.putString("mqtt_user",    currentConfig.mqtt_user);
  preferences.putString("mqtt_pass",    currentConfig.mqtt_pass);
  preferences.putString("cmd_topic",    currentConfig.mqtt_command_topic);
  preferences.putString("state_topic",  currentConfig.mqtt_state_topic);
  preferences.putString("status_topic", currentConfig.mqtt_status_topic);
  preferences.putInt   ("fan_def_spd", currentConfig.fan_default_speed_pct);
  preferences.putBool  ("fan_def_on",  currentConfig.fan_default_on);

  // Log only what changed (mask secrets)
  if (old_mqtt_enabled != currentConfig.mqtt_enabled)
    logPrintf("[%.3f s] NVS updated: mqtt_enabled: %s -> %s\n", t,
              old_mqtt_enabled ? "true" : "false",
              currentConfig.mqtt_enabled ? "true" : "false");

  if (old_mqtt_host != currentConfig.mqtt_host)
    logPrintf("[%.3f s] NVS updated: mqtt_host: '%s' -> '%s'\n", t,
              old_mqtt_host.c_str(), currentConfig.mqtt_host);

  if (old_mqtt_port != currentConfig.mqtt_port)
    logPrintf("[%.3f s] NVS updated: mqtt_port: %d -> %d\n", t,
              old_mqtt_port, currentConfig.mqtt_port);

  if (old_mqtt_user != currentConfig.mqtt_user)
    logPrintf("[%.3f s] NVS updated: mqtt_user: '%s' -> '%s'\n", t,
              old_mqtt_user.c_str(), currentConfig.mqtt_user);

  if ((int)old_mqtt_pass.length() != (int)strlen(currentConfig.mqtt_pass))
    logPrintf("[%.3f s] NVS updated: mqtt_pass length: %d -> %d\n", t,
              (int)old_mqtt_pass.length(), (int)strlen(currentConfig.mqtt_pass));

  if (old_cmd_topic != currentConfig.mqtt_command_topic)
    logPrintf("[%.3f s] NVS updated: cmd_topic: '%s' -> '%s'\n", t,
              old_cmd_topic.c_str(), currentConfig.mqtt_command_topic);

  if (old_state_topic != currentConfig.mqtt_state_topic)
    logPrintf("[%.3f s] NVS updated: state_topic: '%s' -> '%s'\n", t,
              old_state_topic.c_str(), currentConfig.mqtt_state_topic);

  if (old_status_topic != currentConfig.mqtt_status_topic)
    logPrintf("[%.3f s] NVS updated: status_topic: '%s' -> '%s'\n", t,
              old_status_topic.c_str(), currentConfig.mqtt_status_topic);

  if (old_def_spd != currentConfig.fan_default_speed_pct)
    logPrintf("[%.3f s] NVS updated: fan_def_spd: %d -> %d\n", t,
              old_def_spd, currentConfig.fan_default_speed_pct);

  if (old_def_on != currentConfig.fan_default_on)
    logPrintf("[%.3f s] NVS updated: fan_def_on: %s -> %s\n", t,
              old_def_on ? "true" : "false",
              currentConfig.fan_default_on ? "true" : "false");

  preferences.end();
}

void applyConfigToParameters() {
  // Reflect mqtt_enabled into the hidden field (UI checkbox is synced by JS)
  custom_mqtt_enable_hidden.setValue(currentConfig.mqtt_enabled ? "1" : "0", 2);

  // Non‑MQTT first
  int safePct = constrain(currentConfig.fan_default_speed_pct, 0, 100);
  if (safePct > 0 && safePct < PCT_MIN_RUN) safePct = PCT_MIN_RUN;
  char speedBuffer[FAN_DEFAULT_SPEED_PARAM_LEN];
  snprintf(speedBuffer, sizeof(speedBuffer), "%d", safePct);
  custom_fan_def_spd.setValue(speedBuffer, FAN_DEFAULT_SPEED_PARAM_LEN);
  custom_fan_def_on.setValue(currentConfig.fan_default_on ? "true" : "false", FAN_DEFAULT_ON_PARAM_LEN);

  // MQTT block
  custom_mqtt_host.setValue(currentConfig.mqtt_host, MQTT_HOST_PARAM_LEN);
  custom_mqtt_user.setValue(currentConfig.mqtt_user, MQTT_USER_PARAM_LEN);
  custom_mqtt_pass.setValue(currentConfig.mqtt_pass, MQTT_PASS_PARAM_LEN);
  custom_mqtt_cmd_topic.setValue  (currentConfig.mqtt_command_topic, MQTT_TOPIC_PARAM_LEN);
  custom_mqtt_state_topic.setValue(currentConfig.mqtt_state_topic,   MQTT_TOPIC_PARAM_LEN);
  custom_mqtt_status_topic.setValue(currentConfig.mqtt_status_topic, MQTT_TOPIC_PARAM_LEN);
  char portBuffer[MQTT_PORT_PARAM_LEN];
  snprintf(portBuffer, sizeof(portBuffer), "%d", currentConfig.mqtt_port);
  custom_mqtt_port.setValue(portBuffer, MQTT_PORT_PARAM_LEN);
}

bool parseBoolParam(const char* value) {
  if (!value) return false;
  while (*value && isspace(static_cast<unsigned char>(*value))) value++;
  if (*value == '\0') return false;
  char c = static_cast<char>(tolower(static_cast<unsigned char>(*value)));
  if (c == '1' || c == 't' || c == 'y') return true;
  if (c == '0' || c == 'f' || c == 'n') return false;
  if (c == 'o' && value[1] && tolower(static_cast<unsigned char>(value[1])) == 'n') return true; // 'on'
  return false;
}

bool updateConfigFromParameters() {
  logPrintf("[%.3f ms] Entering updateConfigFromParameters()\n", millis() / 1000.0f);
  Config newConfig = currentConfig;

  auto safeCopy = [](char* dest, size_t size, const char* src) {
    if (!src) src = "";
    strncpy(dest, src, size);
    dest[size - 1] = '\0';
  };

  // Checkbox first
  newConfig.mqtt_enabled = parseBoolParam(custom_mqtt_enable_hidden.getValue());

  // MQTT fields
  safeCopy(newConfig.mqtt_host, sizeof(newConfig.mqtt_host), custom_mqtt_host.getValue());
  safeCopy(newConfig.mqtt_user, sizeof(newConfig.mqtt_user), custom_mqtt_user.getValue());
  safeCopy(newConfig.mqtt_pass, sizeof(newConfig.mqtt_pass), custom_mqtt_pass.getValue());
  safeCopy(newConfig.mqtt_command_topic, sizeof(newConfig.mqtt_command_topic), custom_mqtt_cmd_topic.getValue());
  safeCopy(newConfig.mqtt_state_topic,   sizeof(newConfig.mqtt_state_topic),   custom_mqtt_state_topic.getValue());
  safeCopy(newConfig.mqtt_status_topic,  sizeof(newConfig.mqtt_status_topic),  custom_mqtt_status_topic.getValue());

  const char* portValue = custom_mqtt_port.getValue();
  if (portValue && strlen(portValue) > 0) {
    int port = atoi(portValue);
    if (port > 0 && port <= 65535) newConfig.mqtt_port = port;
  } else {
    newConfig.mqtt_port = 1883;
  }

  // Non‑MQTT: default speed and ON flag
  const char* speedValue = custom_fan_def_spd.getValue();
  if (speedValue && strlen(speedValue) > 0) {
    newConfig.fan_default_speed_pct = constrain(atoi(speedValue), 0, 100);
  }
  if (newConfig.fan_default_speed_pct > 0 && newConfig.fan_default_speed_pct < PCT_MIN_RUN) {
    newConfig.fan_default_speed_pct = PCT_MIN_RUN;
  }
  newConfig.fan_default_on = parseBoolParam(custom_fan_def_on.getValue());

  bool changed =
    newConfig.mqtt_enabled != currentConfig.mqtt_enabled ||
    strcmp(newConfig.mqtt_host, currentConfig.mqtt_host) != 0 ||
    strcmp(newConfig.mqtt_user, currentConfig.mqtt_user) != 0 ||
    strcmp(newConfig.mqtt_pass, currentConfig.mqtt_pass) != 0 ||
    strcmp(newConfig.mqtt_command_topic, currentConfig.mqtt_command_topic) != 0 ||
    strcmp(newConfig.mqtt_state_topic,   currentConfig.mqtt_state_topic)   != 0 ||
    strcmp(newConfig.mqtt_status_topic,  currentConfig.mqtt_status_topic)  != 0 ||
    newConfig.mqtt_port != currentConfig.mqtt_port ||
    newConfig.fan_default_speed_pct != currentConfig.fan_default_speed_pct ||
    newConfig.fan_default_on != currentConfig.fan_default_on;

  if (changed) {
    currentConfig = newConfig;
    lastUserPercent = newConfig.fan_default_speed_pct > 0 ? newConfig.fan_default_speed_pct : 0;
  }

  applyConfigToParameters();
  return changed;
}

// ========= PWM helpers =========
int percentToDuty(int pct) {
  pct = constrain(pct, 0, 100);
  if (pct > 0 && pct < PCT_MIN_RUN) pct = PCT_MIN_RUN;
  int duty = (int)round((pct / 100.0f) * ((1 << PWM_RES_BITS) - 1));
  return constrain(duty, 0, (1 << PWM_RES_BITS) - 1);
}

int invertDuty(int duty) {
  const int DUTY_MAX = (1 << PWM_RES_BITS) - 1;
  return DUTY_MAX - constrain(duty, 0, DUTY_MAX);
}

// void writeDutyActiveLow(int dutyActiveHigh) {
//   int dutyActiveLow = invertDuty(dutyActiveHigh);
//   ledcWrite(pwmChannel, dutyActiveLow);
//   currentDuty = dutyActiveHigh;
// }

void writeDutyActiveLow(int dutyActiveHigh) {
  int dutyActiveLow = invertDuty(dutyActiveHigh);
#if defined(ARDUINO_ESP32C3_DEV)
  ledcWrite(LEDC_CHANNEL, dutyActiveLow);      // C3 舊 API：用 channel
#else
  ledcWrite(FAN_PWM_PIN, dutyActiveLow);     // C6 新 API：用 pin
#endif
  currentDuty = dutyActiveHigh;
}
 
// ========= MQTT‑aware publishers =========
void publishStateFromDuty(int dutyActiveHigh) {
  if (!currentConfig.mqtt_enabled) return; // MQTT disabled => no publish

  if (!mqtt.connected()) {
    pendingDutyActiveHigh = dutyActiveHigh;
    mqttStateDirty = true;
    ensureMqtt();
    if (!mqtt.connected()) {
      return;
    }
  }

  const int DUTY_MAX = (1 << PWM_RES_BITS) - 1;
  float percent = 100.0f * dutyActiveHigh / DUTY_MAX;
  int setpoint = constrain(lastUserPercent, 0, 100);
  char payload[160];
  snprintf(payload, sizeof(payload), "{\"duty\":%d,\"percent\":%.1f,\"setpoint\":%d}", dutyActiveHigh, percent, setpoint);

  if (!mqtt.publish(currentConfig.mqtt_state_topic, payload, true)) {
    pendingDutyActiveHigh = dutyActiveHigh;
    mqttStateDirty = true;
    return;
  }
  mqttStateDirty = false;
  mqtt.loop();
}

void publishMqttStatus(const char* status) {
  if (!currentConfig.mqtt_enabled) return;
  if (!mqtt.connected() || status == nullptr) return;
  mqtt.publish(currentConfig.mqtt_status_topic, status, true);
  mqtt.loop();
}

// ========= Fan control =========
bool tryParseInt(const char* s, int& out) {
  char* endp = nullptr;
  long v = strtol(s, &endp, 10);
  if (endp == s || *endp != '\0') return false;
  out = (int)v;
  return true;
}

bool tryParseJsonPercent(const String& s, int& outPercent) {
  int idx = s.indexOf("speed");
  if (idx < 0) idx = s.indexOf("percent");
  if (idx < 0) return false;
  int colon = s.indexOf(':', idx);
  if (colon < 0) return false;
  int j = colon + 1;
  while (j < (int)s.length() && isspace((unsigned char)s[j])) j++;
  int start = j;
  while (j < (int)s.length() && (isdigit((unsigned char)s[j]) || s[j] == '.')) j++;
  String numStr = s.substring(start, j);
  outPercent = (int)round(numStr.toFloat());
  return true;
}

bool parseSpeedCommand(const char* payload, int& outPercent) {
  String s = String(payload);
  s.trim();

  if (s.startsWith("RAW:") || s.startsWith("raw:")) {
    int v;
    if (tryParseInt(s.substring(4).c_str(), v)) {
      const int DUTY_MAX = (1 << PWM_RES_BITS) - 1;
      outPercent = (int)round(100.0f * v / DUTY_MAX);
      return true;
    }
    return false;
  }

  if (s.startsWith("{") && s.endsWith("}")) {
    int pct;
    if (tryParseJsonPercent(s, pct)) {
      outPercent = constrain(pct, 0, 100);
      return true;
    }
    return false;
  }

  int val;
  if (tryParseInt(s.c_str(), val)) {
    if (val <= 100) {
      outPercent = constrain(val, 0, 100);
    } else {
      const int DUTY_MAX = (1 << PWM_RES_BITS) - 1;
      outPercent = (int)round(100.0f * constrain(val, 0, DUTY_MAX) / DUTY_MAX);
    }
    return true;
  }

  return false;
}

void mqttCallback(char* topic, byte* payload, unsigned int length) {
  if (!currentConfig.mqtt_enabled) return;
  String msg;
  msg.reserve(length + 1);
  for (unsigned int i = 0; i < length; i++) msg += (char)payload[i];

  int percent;
  if (parseSpeedCommand(msg.c_str(), percent)) {
    handleFanSpeed(percent);
  }
}
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
void loop() {
  wl_status_t currentStatus = WiFi.status();
  if (currentStatus != lastWifiStatus) {
    lastWifiStatus = currentStatus;
    logPrintf("[%lu ms] WiFi status changed: %d\n", millis(), currentStatus);
    if (currentStatus != WL_CONNECTED) {
      mqttWasConnected = false;
    }
  }

  if (currentStatus == WL_CONNECTED) {
    if (currentConfig.mqtt_enabled) {
      if (!mqtt.connected()) ensureMqtt();
      mqtt.loop();
    } else {
      if (mqtt.connected()) {
        // Respect new toggle: disconnect if previously connected
        mqtt.disconnect();
        mqttWasConnected = false;
      }
    }
    server.handleClient();

    if (pendingPercentAfterStart > 0 && millis() >= pendingPercentApplyMs && currentPercent > pendingPercentAfterStart) {
      int target = pendingPercentAfterStart;
      pendingPercentAfterStart = 0;
      pendingPercentApplyMs = 0;
      handleFanSpeed(target);
    }
  } else {
    WiFi.reconnect();
  }
  ArduinoOTA.handle();
  delay(2);

}

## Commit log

2025-10-10 V1.0 1st Released
    [A01 - P01-1.STL, A01 - P02-1.STL, A01 - P03-1.STL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]
2025-12-27 V1.3 Add code for Xiao ESP32C6
    [Bambu filter.3mf]
